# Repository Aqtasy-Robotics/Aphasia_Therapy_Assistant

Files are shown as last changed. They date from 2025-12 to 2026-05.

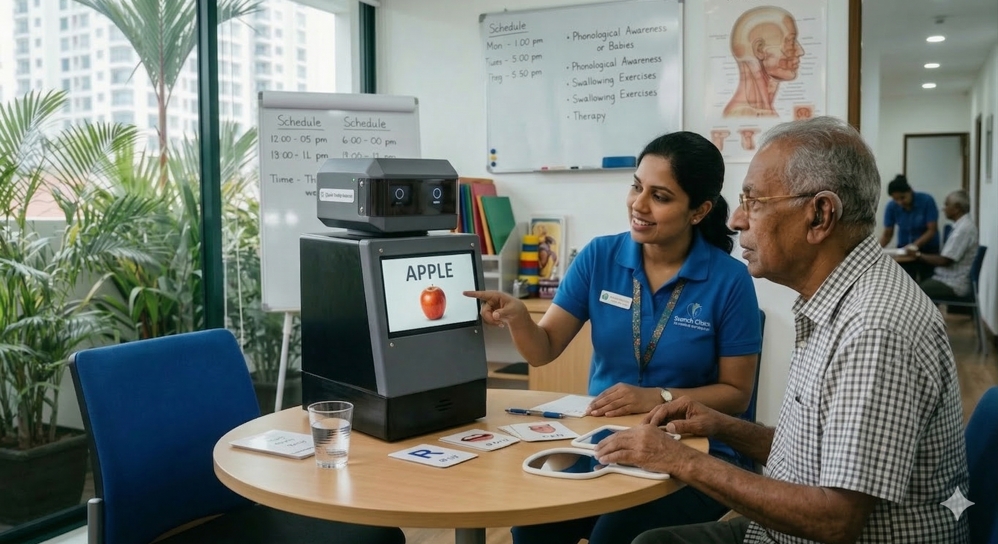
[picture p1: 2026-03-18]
frontend/src/assets/authentication_bgimage.png

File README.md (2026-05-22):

# Waabi — Aphasia Therapy Assistant

> **An AI-powered robotic companion that supports aphasia recovery through structured, conversational speech therapy sessions.**

---

## Table of Contents

- [Overview](#overview)
- [Features](#features)
- [Architecture](#architecture)
- [Repository Layout](#repository-layout)
- [Tech Stack](#tech-stack)
- [Getting Started](#getting-started)
  - [Prerequisites](#prerequisites)
  - [Quick Start: Kivy GUI (Robot)](#quick-start-kivy-gui-robot)
  - [Quick Start: FastAPI Bridge](#quick-start-fastapi-bridge)
  - [Quick Start: Frontend Web App](#quick-start-frontend-web-app)
- [Environment Variables](#environment-variables)
- [Data Flow](#data-flow)
- [Supabase Setup](#supabase-setup)

---

## Overview

Aphasia is a language disorder most commonly caused by stroke or brain injury, affecting a person's ability to speak, understand, read, and write. **Waabi** is a robotic therapy assistant designed to deliver consistent, engaging, and data-driven speech therapy exercises — bridging the gap between clinical appointments and at-home rehabilitation.

Waabi combines a LangGraph-based agentic therapy pipeline, a FastAPI communication bridge, a React web portal for therapists and patients, and a touchscreen-capable Kivy GUI that runs directly on the robot's hardware (e.g. a Raspberry Pi).

---

## Features

- **Agentic therapy sessions** — A LangGraph pipeline guides patients through structured speech exercises (perception → analysis → feedback → execution).
- **Real-time voice interaction** — Microphone capture, text-to-speech via Piper, and optional ElevenLabs Conversational AI integration.
- **Session reporting** — Completed sessions are automatically persisted to Supabase for therapist review.
- **Dual interfaces** — A Kivy touchscreen GUI for bedside/robot use and a React web app for therapist and patient portals.
- **Hardware–cloud bridge** — A FastAPI server mediates commands, status updates, UI events, and audio uploads between the robot and the cloud.
- **Progress tracking** — Recharts-powered dashboards in the web app let therapists monitor patient progress over time.
- **Role-based access** — Supabase Auth with protected routes for therapist and patient roles.

---

## Architecture

```
┌─────────────────────────────────────────────────────────┐
│                      Web App (React)                    │
│          Therapist Portal │ Patient Portal              │
└──────────────────┬──────────────────────────────────────┘
                   │ Supabase Auth (anon key)
                   ▼
┌─────────────────────────────────────────────────────────┐
│                   Supabase (PostgreSQL)                  │
│   profiles │ sessions │ session_reports │ robot-audio   │
└───────────────┬─────────────────────────────────────────┘
                │ service role key
                ▼
┌─────────────────────────────────────────────────────────┐
│             FastAPI Bridge  (backend/main.py)            │
│   GET /commands/{device_id}  │  POST /status            │
│   POST /audio/{device_id}    │  POST /ui-events         │
└──────────────────┬──────────────────────────────────────┘
                   │ HTTP polling
                   ▼
┌─────────────────────────────────────────────────────────┐
│         Hardware Execution Agent (Raspberry Pi)          │
│   hardware/execution_agent/main.py  │  run_gui.py       │
│   Kivy Touchscreen GUI + Drivers (speak, listen, UI)    │
└──────────────────┬──────────────────────────────────────┘
                   │
                   ▼
┌─────────────────────────────────────────────────────────┐
│          LangGraph Therapy Agent  (agentic/)             │
│   Perception → Analysis → Feedback → Execution          │
└─────────────────────────────────────────────────────────┘
```

---

## Repository Layout

```
Aphasia_Therapy_Assistant/
├── agentic/                    # LangGraph speech-therapy pipeline + Supabase helpers
│   └── graph.py                # Main session entrypoint (run_session_for_patient)
├── backend/
│   ├── main.py                 # FastAPI bridge: commands, status, audio, UI events
│   ├── requirements.txt
│   └── .env.example
├── frontend/                   # React + Vite web app (therapist / patient portals)
├── hardware/
│   └── execution_agent/        # Robot / Raspberry Pi software
│       ├── main.py             # Polling loop + hardware drivers
│       ├── run_gui.py          # Kivy launcher (therapy GUI + LangGraph)
│       ├── env_bootstrap.py    # .env merge order utility
│       ├── config.json
│       └── .env.example
├── ML/                         # Speech analysis experiments and research
├── integrations/
│   └── elevenlabs_convai/      # ElevenLabs Conversational AI integration
├── pipecat/                    # Optional real-time voice assistant stack
├── supabase/
│   └── migrations/             # SQL migrations (robot_ui_events, pipeline tables, etc.)
├── scripts/                    # Helper shell scripts
├── tests/                      # Test suite (pytest)
├── laptop_server.py            # Convenience server launcher
├── requirements.txt            # Root Python dependencies
├── requirements-dev.txt        # Dev/test dependencies
└── netlify.toml                # Frontend deployment config
```

---

## Tech Stack

| Layer | Technology |
|---|---|
| **Frontend** | React (Vite), TypeScript, Tailwind CSS, Recharts, React Router v6 |
| **Backend / Bridge** | Python, FastAPI, Uvicorn |
| **Therapy Agent** | LangGraph, Groq (LLM inference) |
| **Database & Auth** | Supabase (PostgreSQL), Supabase Storage |
| **Robot GUI** | Python, Kivy, kvlang |
| **TTS** | Piper (local), ElevenLabs (cloud) |
| **CI/CD** | GitHub Actions, Netlify |
| **Testing** | Pytest |

---

## Getting Started

### Prerequisites

- Python 3.10+
- Node.js 18+ (for the frontend)
- A [Supabase](https://supabase.com/) project with the required tables and storage bucket (see [Supabase Setup](#supabase-setup))
- A [Groq](https://console.groq.com/) API key
- PortAudio installed on the robot device (`sudo apt-get install portaudio19-dev`)

---

### Quick Start: Kivy GUI (Robot)

Run from **`hardware/execution_agent/`**:

```bash
python -m venv .venv
source .venv/bin/activate          # Windows: .venv\Scripts\activate
pip install -r requirements.txt

cp .env.example .env               # Fill in SERVER_URL, DEVICE_ID, Supabase & Groq keys
```

> **No microphone / headless testing?** Set `RUN_GUI_SKIP_PORTAUDIO_CHECK=1` in your `.env`.

```bash
python run_gui.py
```

The GUI will prompt for the patient's full name (must match a `profiles.full_name` row with `role = 'patient'` in Supabase). The LangGraph pipeline then runs the session and writes a report to `session_reports` on completion.

`.env` files are merged in this order (later files override earlier ones):

```
repo root .env → backend/.env → agentic/db/.env → execution_agent/.env → hardware/.env
```

---

### Quick Start: FastAPI Bridge

```bash
cd /path/to/Aphasia_Therapy_Assistant
python -m venv .venv
source .venv/bin/activate
pip install -r backend/requirements.txt

# Set SUPABASE_URL and SUPABASE_SERVICE_KEY in .env (repo root or backend/.env)
uvicorn backend.main:app --reload --app-dir .
```

The `--app-dir .` flag ensures `agentic` package imports resolve correctly from the repo root.

---

### Quick Start: Frontend Web App

```bash
cd frontend
npm install
cp .env.example .env.local         # Set VITE_SUPABASE_URL and VITE_SUPABASE_ANON_KEY
npm run dev
```

Open `http://localhost:5173` in your browser.

---

## Environment Variables

### Repo root `.env` *(recommended single source)*

| Variable | Description |
|---|---|
| `SUPABASE_URL` | Your Supabase project URL |
| `SUPABASE_SERVICE_KEY` | Supabase service role key (server-side only) |
| `GROQ_API_KEY` | Groq API key for LLM inference |

### `hardware/execution_agent/.env`

| Variable | Description |
|---|---|
| `SERVER_URL` | URL of the FastAPI bridge |
| `DEVICE_ID` | Stable identifier for the robot (e.g. `robot-pi-001` or a patient UUID) |
| Piper paths | Path to local TTS model files |

### `backend/.env`

| Variable | Description |
|---|---|
| `SUPABASE_URL` | Supabase project URL |
| `SUPABASE_SERVICE_KEY` | Service role key |
| `BRIDGE_PATIENT_PROFILE_ID` | *(Optional)* Patient `profiles.id` UUID. Use when `DEVICE_ID` is a label rather than a UUID; the bridge loads the patient's name for session greetings. |

> **Robot ID vs Patient ID:** `DEVICE_ID` identifies the robot in API paths. For the bridge greeting, either set `BRIDGE_PATIENT_PROFILE_ID` on the server, or set `DEVICE_ID` to the patient's `profiles.id` UUID directly (legacy behaviour).

---

## Data Flow

### A — Kivy GUI Therapy Session *(typical demo / standalone)*

1. Launch `run_gui.py` from `hardware/execution_agent/`.
2. Patient enters their name; the GUI looks up the matching `profiles` row in Supabase.
3. `agentic/graph.py` runs `run_session_for_patient` through the full LangGraph pipeline.
4. On completion, `persist_session_state` writes results to `session_reports`.
5. The FastAPI bridge is **not required** for session persistence in this path.

### B — Execution Agent + FastAPI Polling

1. Start the bridge: `uvicorn backend.main:app --reload --app-dir .`
2. Start the polling agent: `hardware/execution_agent/main.py` (with `polling` enabled in `config.json`).
3. The robot calls `GET /commands/{DEVICE_ID}`, executes actions, then posts to `POST /status`.
4. `POST /status` writes to `session_reports` only when `ack.result` includes `patient_id` and the full expected state fields. For complete session persistence, prefer the Kivy/LangGraph path.

### C — Web App

- `frontend/` authenticates via Supabase Auth using the **anon key** (set in Vite env).
- Therapists can view patient session reports, assign target words, and monitor progress.
- Patients can access their session history and exercises.

---

## Supabase Setup

1. **Apply migrations** from `supabase/migrations/` to your Supabase project (includes `robot_ui_events`, `agent_pipeline_steps`, and others).

2. **Ensure these tables exist:**
   - `profiles` — user accounts with a `role` column (`'therapist'` or `'patient'`) and `full_name`
   - `sessions` — therapy session definitions including `target_words`
   - `session_reports` — completed session results written by the agent

3. **Create a storage bucket** named `robot-audio` if you use robot audio upload functionality.

4. **Configure RLS (Row Level Security)** policies as appropriate for your deployment — therapists should read all patient records; patients should read only their own.

---

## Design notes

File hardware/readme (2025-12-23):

This is the folder for Hardware related work 
The Basic Hardware is to be used 
- Raspberry Pi 4 8GB
- Micro Phone 
- Speaker
- 7 Inch touch display(Body)
- 1.5 Inch OLED display (Face)
- Micro SD Card
- 3D Printed encoluser 
- Cabels,Screws and Nuts
- Power adapter

Raspberry Pi OS Installation Guide

This guide outlines the steps to install Raspberry Pi OS on a Raspberry Pi 4 for headless (remote) access via SSH.
Prerequisites

    Raspberry Pi 4

    MicroSD card (8GB minimum, 16GB+ recommended)

    Computer with SD card reader

    Network connection for initial setup

Installation Steps
1. Prepare Installation Medium

    Install Raspberry Pi Imager

        Download from raspberrypi.com/software

        Available for Windows, macOS, and Linux

    Insert SD Card

        Insert the microSD card into your computer's card reader

2. Configure and Write OS Image

    Launch Raspberry Pi Imager

    Select Device: Choose "Raspberry Pi 4"

    Choose OS: Select "Raspberry Pi OS (other)" → "Raspberry Pi OS Lite" (or your preferred variant)

    Select Storage: Choose your inserted SD card

    Configure Settings (Click gear icon or Ctrl+Shift+X):

        Enable SSH: Set password authentication

        Configure Wi-Fi (optional for wireless setup):

            Enter SSID and password

            Select your country

        Set username and password

        Configure locale settings if needed

    Write Image: Click "WRITE" and confirm to begin writing

3. Boot Raspberry Pi

    Eject SD card safely from your computer

    Insert SD card into Raspberry Pi 4

    Connect power to boot the Raspberry Pi

    Wait 1-2 minutes for initial boot process to complete

4. Remote Access

    SSH Access: Connect using your computer's terminal:
    bash

ssh username@raspberrypi.local

or use the IP address if known:
bash

ssh username@[IP_ADDRESS]

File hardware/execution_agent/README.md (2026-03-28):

# Aphasia Therapy Robot — Execution Agent v1

A Python-based execution agent that runs on a **Raspberry Pi 4**, communicates with a FastAPI backend over HTTP, and controls local hardware to deliver interactive aphasia therapy sessions.

> 📋 **For detailed implementation phases and development roadmap, see [`implementation_plan.md`](implementation_plan.md).**

| Component | Technology |
|---|---|
| TTS | Piper TTS (local ONNX) |
| Comms | HTTP REST polling (httpx → FastAPI) |
| Mic / Speaker | sounddevice + numpy |
| 7" Touch UI | Kivy (framebuffer / KMS) |
| 1.5" OLED Face | luma.oled (I2C or SPI) |
| Head Servos | gpiozero (GPIO 17 pan, GPIO 27 tilt) |

---

## Project Structure

```
execution_agent/
├── .env                       # Server URL, Device ID, model paths
├── config.json                # Polling rates, GPIO pins, volume, OLED addr
├── requirements.txt           # Python dependencies
├── main.py                    # Entry point & orchestrator
├── models/                    # Piper ONNX model files
│   └── en_US-lessac-medium.onnx
├── src/
│   ├── settings.py            # Pydantic settings loader
│   ├── dispatcher.py          # Command → driver router
│   ├── communication/
│   │   ├── api_client.py      # HTTP polling client
│   │   └── models.py          # ExecutionCommand / CommandAck schemas
│   ├── services/
│   │   ├── ear.py             # Microphone input (sounddevice)
│   │   ├── mouth.py           # Piper TTS + speaker output
│   │   ├── face.py            # OLED face expressions (luma.oled)
│   │   └── head.py            # Servo head movement (gpiozero)
│   └── ui/
│       ├── body_app.py        # Kivy 7" touch dashboard
│       └── body_app.kv        # Kivy layout file
├── assets/
│   ├── images/                # Face PNGs, therapy images
│   └── audio/                 # Sound effects
└── scripts/
    ├── install_dependencies.sh  # One-shot Pi setup (apt + venv)
    ├── install_portaudio_apt.sh # Debian/Ubuntu: PortAudio for mic (dev laptop)
    ├── setup.sh                 # Python virtualenv + pip requirements
    ├── run_agent_desktop.sh     # Pi Desktop: main.py + Kivy UI env vars
    ├── aphasia-robot-agent.desktop  # Template launcher (edit paths)
    └── robot.service            # systemd service unit
```

---

## Prerequisites

- **Raspberry Pi 4** (4 GB+ recommended) running **Raspberry Pi OS Lite** (Bookworm 64-bit)
- Python **3.10+** (ships with Bookworm)
- I2C enabled (`sudo raspi-config` → Interface Options → I2C → Enable) when using I2C OLED
- SPI enabled (`sudo raspi-config` → Interface Options → SPI → Enable) when using SPI OLED
- Official 7" touchscreen connected via DSI
- USB microphone + 3.5 mm / USB speaker

---

## Local MCP Server (STDIO)

You can expose local hardware controls as MCP tools for desktop agents.

### Install dependency

```bash
pip install -r requirements.txt
```

### Start MCP server

From `hardware/execution_agent`:

```bash
python -m mcp_server
```

### Tools exposed (v1)

- `health_check`
- `audio_list_devices`
- `audio_listen`
- `audio_speak`
- `ui_start`
- `ui_show`
- `ui_events_read`
- `ui_ready`

### Remote Raspberry Pi (via FastAPI bridge)

Use these from the **laptop** so commands run on the **Pi** (speaker, mic, Kivy). The bridge must be running (`uvicorn backend.main:app`) and the Pi must run `python main.py` with `SERVER_URL` pointing at that bridge.

- `bridge_health_remote`
- `bridge_enqueue_command`
- `bridge_speak_on_robot`
- `bridge_listen_on_robot`
- `bridge_show_ui_on_robot`

Full setup: **[`docs/BRIDGE_AND_MCP.md`](docs/BRIDGE_AND_MCP.md)**.

### Example MCP client command config

```json
{
  "mcpServers": {
    "waabi-hardware-local": {
      "command": "python",
      "args": ["-m", "mcp_server"],
      "cwd": "C:/Users/USER/Desktop/Aqtasy Robotics/Aphasia_Therapy_Assistant/hardware/execution_agent"
    }
  }
}
```

---

## Installation on Raspberry Pi

### 1. Clone the Repository

```bash
cd ~
git clone <your-repo-url> execution_agent
cd execution_agent
```

### 2. Run the System Dependencies Script

```bash
chmod +x scripts/install_dependencies.sh
sudo scripts/install_dependencies.sh
```

This installs the following apt packages (among others):

| Package | Purpose |
|---|---|
| `python3-venv` | Virtual environment support |
| `libportaudio2`, `portaudio19-dev` | PortAudio for sounddevice |
| `libatlas-base-dev` | Optimised BLAS for numpy on ARM |
| `libjpeg-dev`, `libpng-dev` | Image libraries for Pillow |
| `libsdl2-dev`, `libsdl2-image-dev`, `libsdl2-mixer-dev`, `libsdl2-ttf-dev` | SDL2 for Kivy |
| `i2c-tools`, `python3-smbus` | I2C for OLED |
| `libgpiod2` | GPIO for gpiozero |
| `espeak-ng` | Fallback TTS phonemiser (used by Piper) |

### 3. Create a Virtual Environment

```bash
bash scripts/setup.sh
source .venv/bin/activate
```

> **Note:** On the Pi, `numpy` and `scipy` will build from wheels — this can take a few minutes on first install.

### 4. Download the Piper TTS Model

```bash
mkdir -p models
# English (US) — lessac medium quality (recommended for Pi 4)
wget -O models/en_US-lessac-medium.onnx \
  https://huggingface.co/rhasspy/piper-voices/resolve/main/en/en_US/lessac/medium/en_US-lessac-medium.onnx

wget -O models/en_US-lessac-medium.onnx.json \
  https://huggingface.co/rhasspy/piper-voices/resolve/main/en/en_US/lessac/medium/en_US-lessac-medium.onnx.json
```

### 5. Configure Environment Variables

Create a `.env` file at the project root:

```bash
nano .env
```

Minimum variables:

```dotenv
SERVER_URL=http://<your-server-ip>:8000
DEVICE_ID=robot-pi-001
PIPER_MODEL_PATH=/home/pi/execution_agent/models/en_US-lessac-medium.onnx
LOG_LEVEL=INFO
```

### 6. Test the Agent (Phase-by-Phase)

The project is designed to be tested incrementally on the Pi, following the phases outlined in `implementation_plan.md`. This allows you to verify each component before moving to the next.

#### Phase 1: Mock Drivers (No Hardware Required)

Test that the agent boots and all drivers initialize in mock mode:

```bash
python main.py
```

**Expected output:**
```
INFO  | Execution Agent starting…
INFO  | Device: robot-pi-001
INFO  | Server: http://192.168.1.100:8000
INFO  | Drivers loaded (mock mode): ear, mouth, face, head, body
INFO  | Entering idle loop with interval=2.0 s…
```

**Verification checklist:**
- [ ] Agent starts without errors
- [ ] All drivers report "mock mode" in logs
- [ ] Settings load correctly from `.env` and `config.json`
- [ ] Graceful shutdown works (Ctrl+C)

#### Phase 2: API Client & Polling (Requires FastAPI Backend)

**Prerequisites:** A FastAPI backend server running and accessible at `SERVER_URL`.

Test that the agent can poll for commands and send acknowledgements:

```bash
python main.py
```

**Expected behavior:**
- Agent polls `GET /commands/{device_id}` every 2 seconds
- Logs show connection status to the backend
- Commands are received and dispatched (still using mock drivers)
- Acknowledgements are sent back to the server

**Verification checklist:**
- [ ] Agent successfully connects to backend (check `/health` endpoint)
- [ ] Polling loop runs without errors
- [ ] Commands are received and logged
- [ ] Mock drivers execute commands (logged, not hardware)
- [ ] Acknowledgements are sent to `/status` endpoint

**Test with a simple backend:**
```python
# On your laptop/server, run a test FastAPI server
from fastapi import FastAPI
app = FastAPI()

@app.get("/commands/robot-pi-001")
def get_command():
    return {"command_id": "test-1", "action": "speak", "payload": {"text": "Hello"}}

@app.post("/status")
def post_status(ack: dict):
    print(f"Received: {ack}")
    return {"ok": True}
```

#### Phase 3: Audio Hardware (Requires USB Mic + Speaker)

**Prerequisites:** USB microphone and speaker connected to the Pi.

Test real audio input/output:

```bash
python main.py
```

**Verification checklist:**
- [ ] `mouth.speak("Hello")` plays audio through speaker
- [ ] `ear.listen(5)` records 5 seconds from microphone
- [ ] Audio sample rate matches `config.json` (22050 Hz)
- [ ] Piper TTS model loads successfully (< 5 seconds)
- [ ] Recorded audio can be uploaded to backend

**Test commands:**
- Send a `speak` command from backend → verify audio plays
- Send a `listen` command → verify recording works and uploads

#### Phase 4: Kivy UI (Requires 7" Touchscreen)

**Prerequisites:** Official 7" Raspberry Pi touchscreen connected via DSI.

Test the touchscreen dashboard:

```bash
# Ensure display is configured for KMS/DRM
export KIVY_WINDOW=sdl2
export KIVY_GL_BACKEND=sdl2
python main.py
```

**Verification checklist:**
- [ ] Kivy app launches fullscreen on 7" display
- [ ] `show_ui` command updates screen content
- [ ] Touch input is responsive
- [ ] App runs alongside polling loop without blocking

#### Phase 5: GPIO & OLED (Requires Servos + OLED Display)

**Prerequisites:**
- Pan/tilt servos connected to GPIO 17 and 27
- OLED display connected via I2C (address 0x3C)
- I2C enabled: `sudo raspi-config` → Interface Options → I2C → Enable

Test physical hardware:

```bash
# Verify I2C connection first
sudo i2cdetect -y 1  # Should show OLED at 0x3C

python main.py
```

**Verification checklist:**
- [ ] `head.move(pan=45, tilt=0)` physically rotates pan servo
- [ ] `face.show("happy")` displays expression on OLED
- [ ] GPIO pins match `config.json` values
- [ ] Servos respect safety limits (no jitter at rest)
- [ ] OLED initializes cleanly and recovers from bus errors

**Test commands:**
- `move_head` with various pan/tilt values
- `show_face` with different expressions (happy, sad, neutral, etc.)

---

## Testing on Laptop (Development Mode)

You can develop and test on any Linux/macOS/Windows machine. Hardware-dependent libraries (`gpiozero`, `luma.oled`) are automatically mocked when imports fail.

```bash
# Clone & set up
git clone <your-repo-url> execution_agent
cd execution_agent
python3 -m venv .venv && source .venv/bin/activate
pip install -r requirements.txt

# Run with mock drivers (Phase 1 equivalent)
python main.py
```

All drivers will automatically fall back to mock mode, allowing you to test the full command flow without hardware.

### Microphone / `run_gui.py` — PortAudio required

The LangGraph session records audio with **`sounddevice`**, which needs the **PortAudio** system library. `run_gui.py` checks for PortAudio on startup and exits with instructions if it is missing.

**Debian / Ubuntu (one command):**

```bash
cd execution_agent   # folder containing main.py
sudo bash scripts/install_portaudio_apt.sh
```

Or manually: `sudo apt install -y libportaudio2 portaudio19-dev`

Then restart `run_gui.py`. The Pi image script [`scripts/install_dependencies.sh`](scripts/install_dependencies.sh) already includes these packages.

### LangGraph therapy session (`run_gui.py`)

[`run_gui.py`](run_gui.py) loads **repo-root** `../.env` before Kivy starts so **`GROQ_API`**, **`SUPABASE_URL`**, **`SUPABASE_SERVICE_KEY`**, etc. are available when you tap the mic and [`agentic/graph.py`](../agentic/graph.py) runs. Without a valid `.env`, perception (Groq) or Supabase lookups will fail.

From the **repository root** (parent of this folder), you can also use [`../scripts/run_gui_langgraph.sh`](../scripts/run_gui_langgraph.sh) to set `PYTHONPATH` and run the GUI.

### Desktop launcher (full agent + UI + backend)

1. Edit paths in [`scripts/aphasia-robot-agent.desktop`](scripts/aphasia-robot-agent.desktop) (`Exec` and `Path`) to match your install.
2. `chmod +x scripts/run_agent_desktop.sh scripts/aphasia-robot-agent.desktop`
3. Copy the `.desktop` file to `~/Desktop` or `~/.local/share/applications/`, then mark it trusted / allow executing.

[`run_agent_desktop.sh`](scripts/run_agent_desktop.sh) sets `EXECUTION_AGENT_START_UI=1`, Kivy SDL2 env vars, and runs `main.py` (requires `polling.enabled` and `.env` for FastAPI).

### UI events → FastAPI

When polling is enabled, touch events from Kivy are **POST**ed to **`POST /ui-events/{device_id}`** on the backend. The FastAPI app in [`backend/main.py`](../backend/main.py) logs them. Set **`BRIDGE_TEST_SHOW_UI=1`** on the server to return a test `show_ui` command from **`GET /commands/{device_id}`**.

---

## Running as a System Service

### Install the systemd Unit

Edit `scripts/robot.service` if needed so `WorkingDirectory`, `ExecStart`, and `User` match where you cloned the repo (paths must point at the folder that contains `main.py`, `config.json`, and `.venv`).

```bash
cd /home/pi/execution_agent   # your install path
sudo cp scripts/robot.service /etc/systemd/system/
sudo systemctl daemon-reload
sudo systemctl enable robot.service
sudo systemctl start robot.service
```

**OLED face on boot (no backend):** In `config.json` set `"polling": { "enabled": false, ... }` and `"oled": { "standalone_math_eyes": true, ... }` with the same SPI/SH1107 options as `hardware_tests/pan_oled_phase5/test_config.json` (`interface`, `oled_driver`, `rotate`, `eye_layout`, `eyes_bias_x`, GPIO pins). The agent’s main loop stays alive while the OLED task animates; `Restart=always` restarts the process if it ever crashes.

### Check Logs

```bash
sudo journalctl -u robot.service -f
```

---

## Configuration Reference

### `.env`

| Variable | Description | Example |
|---|---|---|
| `SERVER_URL` | FastAPI backend base URL | `http://192.168.1.100:8000` |
| `DEVICE_ID` | Unique robot identifier | `robot-pi-001` |
| `PIPER_MODEL_PATH` | Path to Piper ONNX model | `models/en_US-lessac-medium.onnx` |
| `PIPER_MODEL_CONFIG` | Path to Piper model config JSON | `models/en_US-lessac-medium.onnx.json` |
| `LOG_LEVEL` | Logging verbosity | `DEBUG` / `INFO` / `WARNING` |

### `config.json`

| Section | Key | Default | Description |
|---|-----|---|---|
| `polling` | `interval_seconds` | `2.0` | How often to poll the server |
| `polling` | `enabled` | `true` | Enable/disable backend polling loop |
| `polling` | `timeout_seconds` | `5.0` | HTTP request timeout |
| `polling` | `max_retries` | `3` | Retries before back-off |
| `audio` | `sample_rate` | `22050` | Recording/playback sample rate |
| `audio` | `channels` | `1` | Mono |
| `audio` | `volume` | `0.8` | Playback gain (0.0–1.0) |
| `gpio` | `servo_pan_pin` | `17` | BCM pin for pan servo |
| `gpio` | `servo_min_pulse_width` | `0.0005` | Pan servo minimum pulse width |
| `gpio` | `servo_max_pulse_width` | `0.0025` | Pan servo maximum pulse width |
| `oled` | `i2c_address` | `0x3C` | OLED I2C address |
| `oled` | `interface` | `i2c` | OLED bus interface (`i2c` or `spi`) |
| `oled` | `oled_driver` | `ssd1351` | Display controller driver |
| `oled` | `spi_port` / `spi_device` | `0` / `0` | Linux SPI bus and CS |
| `oled` | `spi_gpio_dc` / `spi_gpio_rst` | `24` / `25` | GPIO pins for D/C and RESET |
| `oled` | `standalone_math_eyes` | `false` | Run local eye animation without backend commands |
| `oled` | `width` / `height` | `128` / `128` | OLED resolution |
| `display` | `width` / `height` | `800` / `480` | Kivy display resolution |

---

## Wiring Diagram (Quick Reference)

```
Raspberry Pi 4 GPIO Header
──────────────────────────
Pin 1  (3.3V)     → OLED VCC
Pin 3  (GPIO 2)   → OLED SDA  (I2C Data)
Pin 5  (GPIO 3)   → OLED SCL  (I2C Clock)
Pin 6  (GND)      → OLED GND
Pin 11 (GPIO 17)  → Pan Servo Signal   (Orange wire)
Pin 13 (GPIO 27)  → Tilt Servo Signal  (Orange wire)
Pin 2  (5V)       → Servo VCC          (Red wire, via external 5V supply recommended)
Pin 14 (GND)      → Servo GND          (Brown wire)
USB Port          → USB Microphone
3.5mm Jack / USB  → Speaker
DSI Port          → 7" Official Touchscreen
```

> ⚠️ **Important:** Power servos from an external 5V supply to avoid brownouts on the Pi. Share a common ground with the Pi.

### SPI OLED Quick Wiring (7-pin module)

For a 7-pin SPI OLED (`GND, VCC, D0, D1, RST, DC, CS`) on Raspberry Pi:

- `GND` -> Pi GND
- `VCC` -> Pi 3.3V (or module-safe 5V if your board supports it)
- `D0 (CLK)` -> GPIO11 / SPI0 SCLK (physical pin 23)
- `D1 (MOSI)` -> GPIO10 / SPI0 MOSI (physical pin 19)
- `RST` -> configurable GPIO (default in config: BCM 25 / physical pin 22)
- `DC` -> configurable GPIO (default in config: BCM 24 / physical pin 18)
- `CS` -> GPIO8 / SPI0 CE0 (physical pin 24, `spi_device=0`) or GPIO7 / CE1 (`spi_device=1`)

---

## License

This project is for academic / research use as part of the Aphasia Therapy Robot system.

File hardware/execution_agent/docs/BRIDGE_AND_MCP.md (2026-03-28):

# Laptop agents (MCP) + Raspberry Pi UI / mic / speaker

This flow uses the **FastAPI bridge** (`backend/main.py`) as a command queue:

1. **Laptop:** Claude / MCP calls `bridge_*_on_robot` tools → HTTP `POST /commands/{device_id}/enqueue`
2. **Bridge:** Stores commands in memory (FIFO per `device_id`)
3. **Pi:** `execution_agent/main.py` polls `GET /commands/{device_id}` → `Dispatcher` runs `speak` / `listen` / `show_ui` **on the Pi** (speaker, mic, Kivy)

## Prerequisites

- Same repo on laptop and Pi (or copy `hardware/execution_agent` + `backend` as needed)
- Pi and laptop on the same LAN (or VPN)
- Root `.env` with `SUPABASE_URL` and `SUPABASE_SERVICE_KEY` (for the bridge server)
- Optional: `BRIDGE_COMMAND_API_KEY` (same value in bridge env and laptop `execution_agent/.env` for MCP)

## 1) Run the bridge on the **laptop** (or any server the Pi can reach)

From repo root:

```powershell
cd "C:\Users\USER\Desktop\Aqtasy Robotics\Aphasia_Therapy_Assistant"
python -m venv .venv
.\.venv\Scripts\Activate.ps1
pip install -r backend/requirements.txt
pip install -r requirements.txt
```

If `backend/requirements.txt` is minimal, ensure you have: `fastapi`, `uvicorn`, `supabase`, `python-dotenv`, `pydantic` (install errors will tell you).

Start API (replace `0.0.0.0` so the Pi can connect; use your laptop LAN IP in Pi `.env`):

```powershell
uvicorn backend.main:app --host 0.0.0.0 --port 8000
```

Optional security (recommended):

```dotenv
# repo root .env or backend/.env
BRIDGE_COMMAND_API_KEY=your-long-random-secret
```

## 2) Configure the **Raspberry Pi** `execution_agent`

Edit `hardware/execution_agent/.env`:

- `SERVER_URL=http://<LAPTOP_LAN_IP>:8000` (must match where uvicorn runs)
- `DEVICE_ID=robot-pi-001` (or any stable label; must match what you pass from MCP)
- `PIPER_MODEL_PATH=...` (path to Piper ONNX on the Pi)
- Start Kivy with the agent:

```dotenv
EXECUTION_AGENT_START_UI=1
```

Edit `hardware/execution_agent/config.json` → ensure `polling.enabled` is `true` (default in your template).

### Run on the Pi (must run **on the Raspberry Pi**)

```bash
cd ~/Aphasia_Therapy_Assistant/hardware/execution_agent
source .venv/bin/activate   # or your venv
export EXECUTION_AGENT_START_UI=1
python main.py
```

The Pi will poll the bridge and execute commands on **local** speaker, mic, and Kivy.

## 3) Configure **MCP on the laptop** (Claude Desktop / Cursor)

Same machine that runs MCP needs `hardware/execution_agent/.env`:

- `SERVER_URL=http://<LAPTOP_LAN_IP>:8000` (same bridge URL; can be `http://127.0.0.1:8000` if MCP and uvicorn are on the same PC)
- `DEVICE_ID=robot-pi-001` (same as Pi)
- If you set `BRIDGE_COMMAND_API_KEY` on the server, add the same to this `.env`:

```dotenv
BRIDGE_COMMAND_API_KEY=your-long-random-secret
```

Run MCP:

```powershell
cd "C:\Users\USER\Desktop\Aqtasy Robotics\Aphasia_Therapy_Assistant\hardware\execution_agent"
python -m mcp_server
```

Or register `python -m mcp_server` in Claude Desktop with `cwd` set to this folder.

## 4) MCP tools to use (remote Pi)

| Tool | Purpose |
|---|---|
| `bridge_health_remote` | Check bridge `GET /health` |
| `bridge_speak_on_robot` | TTS on Pi speaker |
| `bridge_listen_on_robot` | Record on Pi mic (upload depends on `ear` + backend) |
| `bridge_show_ui_on_robot` | Kivy screen on Pi |
| `bridge_enqueue_command` | Generic `speak` / `listen` / `show_ui` / … |

Local-only tools (`ui_show`, `audio_speak`, …) still affect **only the machine running MCP**, not the Pi.

## 5) LangGraph / “agent on laptop”

This bridge queue drives **hardware** on the Pi. **LangGraph** (`agentic/graph.py`) is not automatically started by MCP. To run therapy logic on the laptop, call your Python entrypoint separately (e.g. `run_session_for_patient`) or add a future MCP tool that wraps it; use `bridge_speak_on_robot` / `bridge_listen_on_robot` from your agent code when you want Pi I/O.

## Troubleshooting

- **Pi never gets commands:** `SERVER_URL` on Pi must reach the laptop; firewall must allow port 8000; `DEVICE_ID` must match enqueue path.
- **401 on enqueue:** Set `BRIDGE_COMMAND_API_KEY` on server and same key in laptop `.env` for MCP.
- **No UI on Pi:** Set `EXECUTION_AGENT_START_UI=1` and ensure Kivy/display works on the Pi.

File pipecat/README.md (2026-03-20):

# Pipecat Aphasia Voice Assistant

This module provides a Pipecat-based, real-time voice assistant designed for **post-therapy support** for aphasia and related speech disorders.

It is intentionally tuned for:

- short, clear responses
- one-question-at-a-time pacing
- confirmation loops when speech is unclear
- supportive coaching (not diagnosis)

## What this bot does

- Listens to patient speech (Deepgram STT)
- Generates supportive responses (Groq LLM)
- Speaks back naturally (Cartesia TTS)
- Runs over Pipecat WebRTC transport for low-latency voice interaction

## Safety boundaries

The agent is configured to:

- avoid medical diagnosis or medication advice
- escalate to emergency services/caregiver language for urgent warning signs
- maintain a therapist-aligned coaching tone

This is **not** a replacement for clinician care.

## Project files

- `bot.py` - main Pipecat voice agent
- `.env.example` - required API variables
- `requirements.txt` - Python dependencies

## Quick start (Windows PowerShell)

From this folder:

```powershell
python -m venv .venv
.\.venv\Scripts\Activate.ps1
pip install -r requirements.txt
Copy-Item .env.example .env
```

Open `.env` and set:

- `DEEPGRAM_API_KEY`
- `GROQ_API_KEY`
- `CARTESIA_API_KEY`

Then run:

```powershell
python bot.py
```

You should see a local WebRTC URL in logs (typically `http://localhost:7860/client`) to connect from browser.

## Configuration for therapists

Use environment variables to tailor behavior:

- `GROQ_MODEL` - e.g. "llama-3.3-70b-versatile"
- `THERAPY_FOCUS` - e.g. "word retrieval and sentence initiation"
- `ASSISTANT_LANGUAGE_HINT` - e.g. "Use simple Spanish and short phrases"
- `ASSISTANT_NAME` - custom assistant name for familiarity

## Next improvements you can add

- Persist session summaries to your backend for therapist review
- Add personalized phrase banks from each patient's home program
- Add visual fallback prompts when voice confidence is low
- Add caregiver mode for guided home practice

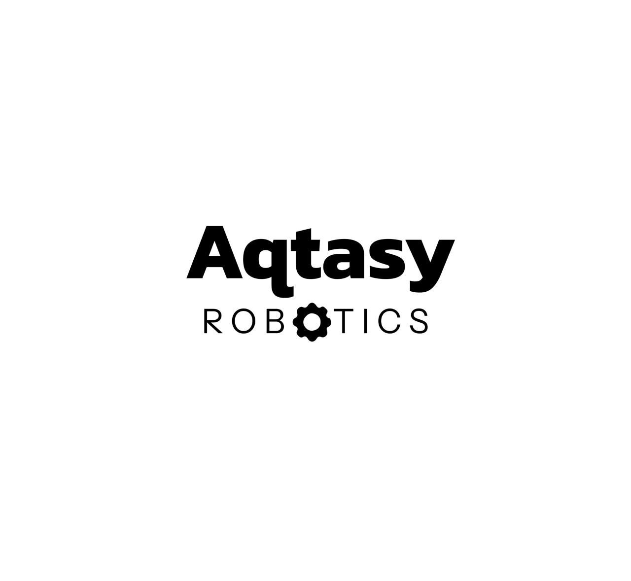
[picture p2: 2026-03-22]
hardware/execution_agent/WhatsApp Image 2026-03-22 at 8.28.11 PM.jpeg

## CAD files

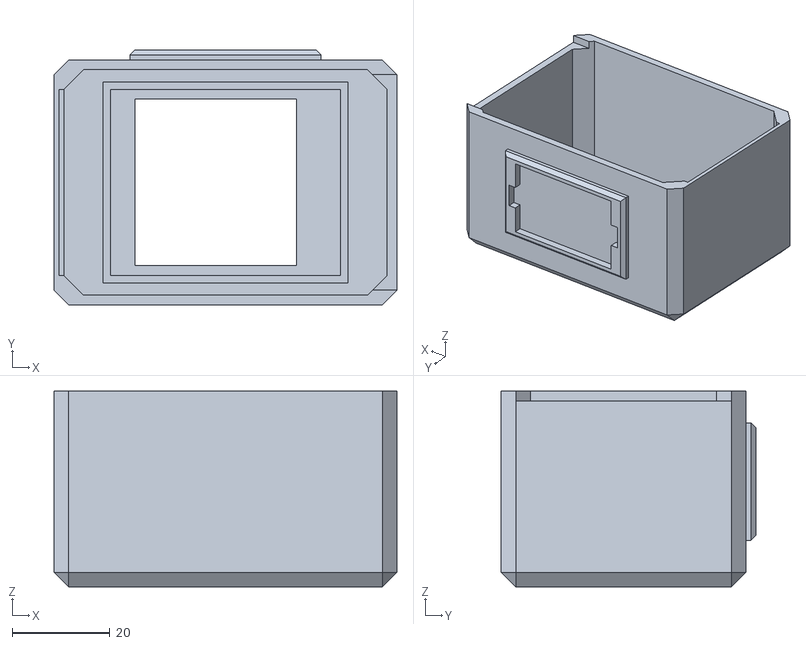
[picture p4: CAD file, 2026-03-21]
hardware/Waabi_design/Skeleton_frameV1/waabi_frame-Body011.stl
70.0 x 52.0 x 40.0

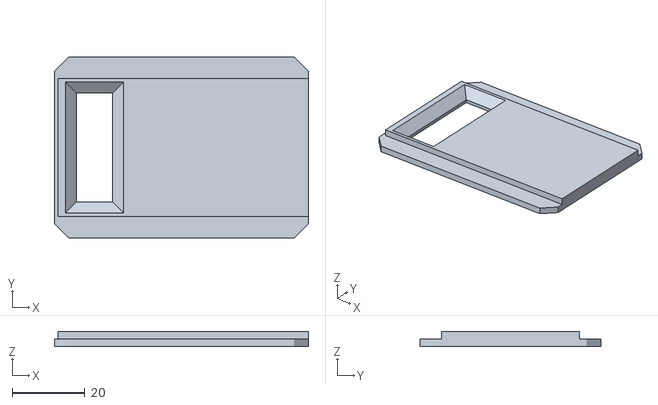
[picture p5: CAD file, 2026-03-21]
hardware/Waabi_design/Skeleton_frameV1/waabi_frame-Body012.stl
70.0 x 50.0 x 4.00

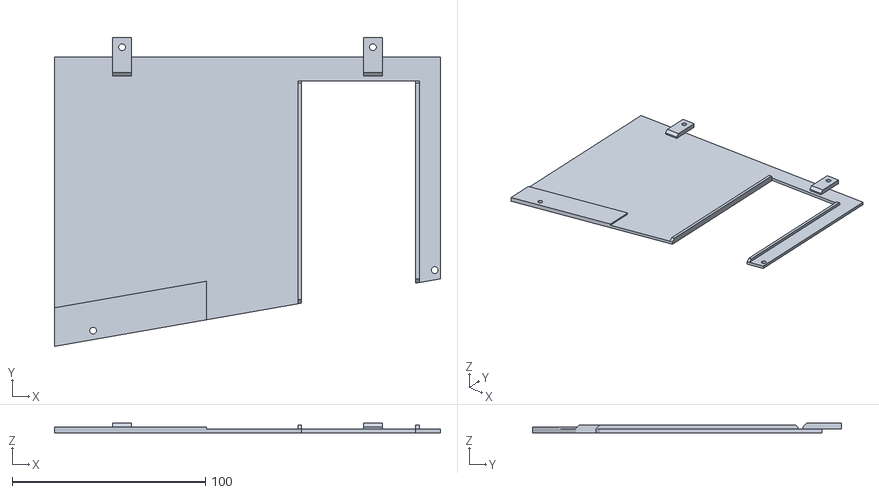
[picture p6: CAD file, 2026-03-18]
hardware/Waabi_design/Skeleton_frameV1/waabi_frame-leftside_plate.stl
200.0 x 160.0 x 5.00

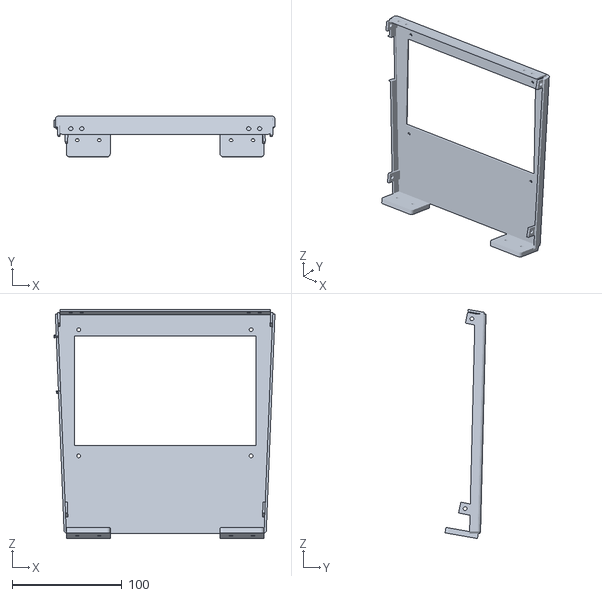
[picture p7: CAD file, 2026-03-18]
hardware/Waabi_design/Skeleton_frameV1/waabi_frame-Front_plate.stl
201.2 x 37.4 x 208.6

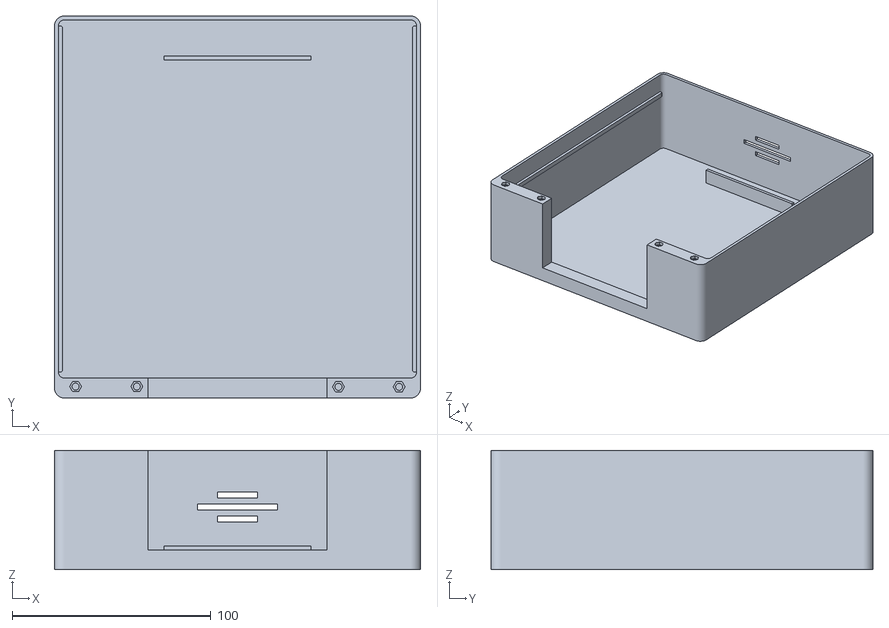
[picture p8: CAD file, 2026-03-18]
hardware/Waabi_design/Skeleton_frameV1/waabi_frame-BaseV2.stl
184.0 x 192.0 x 60.0

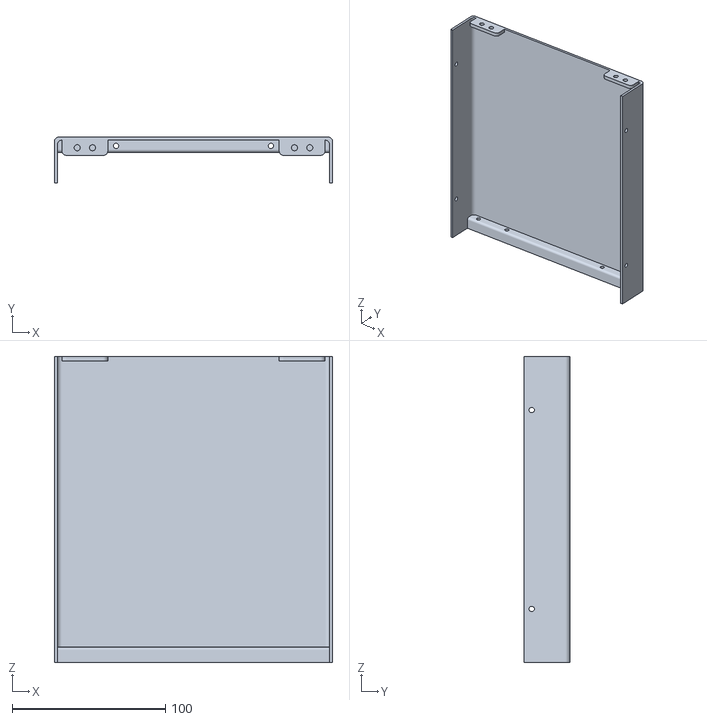
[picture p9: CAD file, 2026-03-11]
hardware/Waabi_design/Skeleton_frameV1/waabi_frame-Back_plate.stl
182.0 x 30.0 x 200.0

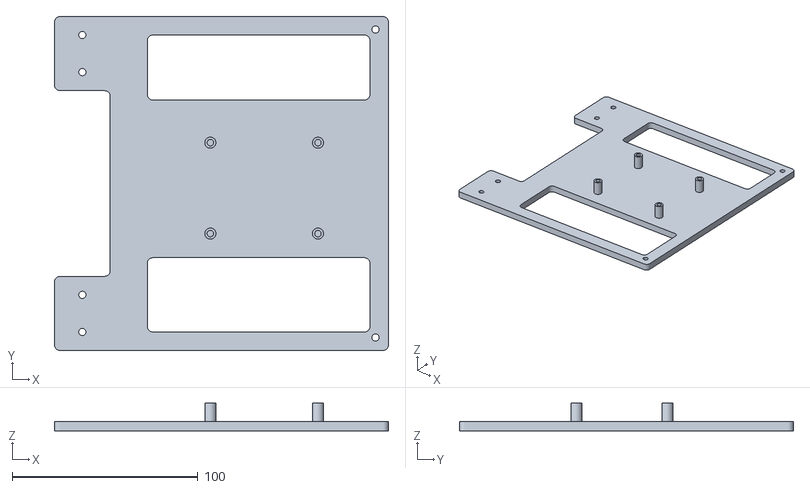
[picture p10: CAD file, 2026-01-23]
hardware/Waabi_design/Skeleton_frameV1/waabi_base_skeleton.stl
180.0 x 180.0 x 15.0

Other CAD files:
hardware/Waabi_design/Skeleton_frameV1/waabi_frame-Body.stl

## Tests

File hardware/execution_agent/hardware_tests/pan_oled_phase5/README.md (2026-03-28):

Pan+Eyes Physical Test (Phase 5)
================================

This folder is meant to be copied to your Raspberry Pi *as-is*.
It provides two small scripts:
- `test_pan_servo.py`: sweep the pan servo and verify clamping + movement
- `test_oled_eyes.py`: render procedural (code-generated) eyes to the OLED

Files you should upload/copy:
- `test_pan_servo.py`
- `test_oled_eyes.py`
- `test_config.json`
- `requirements.txt`
- this `README.md`

1) Copy to the Pi
-------------------
From your dev machine, run something like:

```bash
scp -r "execution_agent/hardware_tests/pan_oled_phase5" pi@<PI_IP>:~/
```

Then `cd` into the folder on the Pi:

```bash
cd ~/pan_oled_phase5
```

2) Install dependencies
------------------------
```bash
python3 -m pip install --upgrade pip
pip install -r requirements.txt
```

If you already have them installed system-wide, this can be skipped.

3) Edit `test_config.json` (if needed)
---------------------------------------
Defaults match the repo `execution_agent/config.json`.
If your wiring differs, update:
- `gpio.servo_pan_pin`
- `gpio.servo_min_pulse_width` / `gpio.servo_max_pulse_width`
- `oled.interface` (`i2c` or `spi`)
- `oled.i2c_address` / `oled.rotate` / `oled_driver` (if needed)
- SPI modules: `oled.spi_port`, `oled.spi_device`, `oled.spi_gpio_dc`, `oled.spi_gpio_rst`
- **Dual OLED mode:** if `oled_left` + `oled_right` exist in config, the script drives
  two displays and renders **one eye per display**.
  - Left eye display: `oled_left` (recommended CE0 / `spi_device: 0`)
  - Right eye display: `oled_right` (recommended CE1 / `spi_device: 1`)
  - Recommended dual pin map:
    - shared: `SCL->GPIO11`, `SDA->GPIO10`, `VCC->3V3`, `GND->GND`
    - left: `CS->GPIO8(CE0)`, `DC->GPIO24`, `RST->GPIO25`
    - right: `CS->GPIO7(CE1)`, `DC->GPIO23`, `RST->GPIO22`
- **Orientation:** `oled.rotate` — luma uses `0..3` (steps of 90° clockwise). Try `1`, `2`, or `3` if the face is sideways in your enclosure.
- **Eye position:** `oled.eye_layout` — `horizontal` (default) or `vertical` (stacked, good for portrait mounts). `oled.eyes_bias_x` — `-1.0`..`1.0`; **negative shifts both eyes left**, positive shifts right.

4) Test the pan servo
----------------------
```bash
python3 test_pan_servo.py
```

Optional flags:
- `--duration_s` (default: sweep once)
- `--pan_min`, `--pan_max`, `--step_deg`
- `--speed` (`slow|normal|fast`)

5) Test the OLED (eyes)
------------------------
```bash
python3 test_oled_eyes.py --duration 5.0 --expression neutral
```

For dual OLED (`oled_left` + `oled_right` in config), same command works and renders
one eye on each display:

```bash
python3 test_oled_eyes.py --config test_config.json --duration 15 --expression auto
```

Optional flags:
- `--duration` seconds (default: 3.0)
- `--expression` one of `neutral|happy|sad|thinking|surprised|listening` (default: auto cycle)
- `--gaze_x`, `--gaze_y` in range `[-1.0, 1.0]`

6) Troubleshooting quick checks
--------------------------------
Servo issues:
- Double-check the servo signal wire is on the BCM pin you set in `gpio.servo_pan_pin`.
- Ensure the servo has a suitable 5V supply (do not power servos from the Pi directly if unstable).

OLED issues:

- **`ModuleNotFoundError: No module named 'RPi'`** (SPI path): install GPIO support in the same venv — `pip install RPi.GPIO` (also listed in `requirements.txt`). Luma uses **RPi.GPIO** for SPI **DC** and **RST** lines.

- **Static / snow on a 128x128 blue 7-pin SPI board:** that panel is almost always **SH1107** (monochrome), not **SSD1351** (color). Use `"oled_driver": "sh1107"` with `"interface": "spi"`. Using `ssd1351` on SH1107 hardware produces garbage pixels.
- Confirm I2C is enabled: `sudo raspi-config` -> Interface Options -> I2C -> Enable.
- Confirm the OLED address (common is `0x3C` or `0x3D`).
- **`GME128128-01` / 1.5\" SH1107 IIC:** use `"oled_driver": "sh1107"`. The script uses
  the **u8g2** `SH1107 128x128` init (not luma/Adafruit). Set `"column_x_offset": 96`
  (default); if the image is horizontally wrong, try **`0`** (see u8g2 issue \#2581).
- Permissions: user must access `/dev/i2c-*` — `sudo usermod -aG i2c $USER` then re-login,
  or run once with `sudo` to verify.
- Slow bus: in `/boot/firmware/config.txt` add `dtparam=i2c_arm_baudrate=50000` and reboot.
- If your display controller is not SSD1351, set `oled_driver` in `test_config.json`:
  - `ssd1351` (default)
  - `sh1106`

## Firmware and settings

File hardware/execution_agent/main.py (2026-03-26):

"""Main entry point for the Aphasia Therapy Robot Execution Agent."""

import asyncio
import os
import signal
import sys
from pathlib import Path

# Enable Kivy virtual keyboard for touchscreen text input (dock = keyboard at bottom).
os.environ.setdefault("KCFG_KIVY_KEYBOARD_MODE", "dock")
os.environ.setdefault("KCFG_KIVY_KEYBOARD_LAYOUT", "qwerty")

from loguru import logger

from src.communication.api_client import ApiClient
from src.communication.models import ActionEnum
from src.dispatcher import Dispatcher
from src.services.audio_utils import list_audio_devices
from src.services.ear import listen
from src.services.face import (
    maybe_start_standalone_face,
    show_face,
    shutdown_face,
    stop_standalone_face,
)
from src.services.head import move_head, shutdown_head
from src.services.mouth import speak
from src.ui.body_app import (
    dequeue_ui_events,
    has_pending_ui_events,
    maybe_start_ui_from_env,
    show_ui,
)
from src.settings import load_settings_or_exit

# Global state
running = True


def handle_shutdown(signum, frame):
    """Handle shutdown signals gracefully."""
    global running
    logger.info(f"Received signal {signum}, initiating graceful shutdown...")
    running = False


def setup_logging(log_level: str, project_root: Path):
    """
    Configure loguru logger with console and file sinks.

    Args:
        log_level: Logging level (DEBUG, INFO, WARNING, ERROR)
        project_root: Root directory of the project
    """
    # Remove default logger
    logger.remove()

    # Console sink with color and formatting
    logger.add(
        sys.stderr,
        format="<green>{time:YYYY-MM-DD HH:mm:ss}</green> | <level>{level: <8}</level> | <level>{message}</level>",
        level=log_level,
        colorize=True,
    )

    # File sink - try /var/log first, fallback to logs/ directory
    log_file = Path("/var/log/execution_agent.log")
    if not log_file.parent.exists() or not os.access(log_file.parent, os.W_OK):
        # Fallback to project logs directory
        logs_dir = project_root / "logs"
        logs_dir.mkdir(exist_ok=True)
        log_file = logs_dir / "execution_agent.log"

    logger.add(
        log_file,
        format="{time:YYYY-MM-DD HH:mm:ss} | {level: <8} | {message}",
        level=log_level,
        rotation="10 MB",
        retention="5",
        compression="zip",
    )


async def main():
    """Main async entry point."""
    global running

    # Get project root (directory containing main.py)
    project_root = Path(__file__).parent

    # Load settings (exits on error)
    logger.info("Loading configuration...")
    settings = load_settings_or_exit()

    # Setup logging with loaded log level
    setup_logging(settings.log_level, project_root)
    maybe_start_ui_from_env(project_root)

    # Print startup banner
    banner = f"""
╔════════════════════════════════════════╗
║   Aphasia Therapy Robot - Agent v1    ║
╚════════════════════════════════════════╝
Device ID: {settings.device_id}
Server URL: {settings.server_url}
Polling Interval: {settings.polling.interval_seconds}s
Log Level: {settings.log_level}
"""
    logger.info(banner)

    # Log configuration summary
    logger.info("Configuration loaded successfully")
    logger.debug(f"Audio sample rate: {settings.audio.sample_rate} Hz")
    logger.debug(f"GPIO pin - Pan: {settings.gpio.servo_pan_pin}")
    logger.debug(f"OLED: {settings.oled.width}x{settings.oled.height} "
                f"at {settings.oled.i2c_address}")
    logger.debug(
        "OLED interface={} driver={} rotate={} eye_layout={} eyes_bias_x={} standalone_math_eyes={}",
        settings.oled.interface,
        settings.oled.oled_driver,
        settings.oled.rotate,
        settings.oled.eye_layout,
        settings.oled.eyes_bias_x,
        settings.oled.standalone_math_eyes,
    )

    # List audio devices and log selected devices
    logger.info("Audio configuration:")
    logger.info(f"  Sample rate: {settings.audio.sample_rate} Hz")
    logger.info(f"  Channels: {settings.audio.channels}")
    logger.info(f"  Volume: {settings.audio.volume}")
    logger.info(f"  Input device: {settings.audio.input_device or 'default'}")
    logger.info(f"  Output device: {settings.audio.output_device or 'default'}")
    list_audio_devices()

    maybe_start_standalone_face(settings)

    api_client = None
    dispatcher = None

    if settings.polling.enabled:
        # Initialise API client and dispatcher
        api_client = ApiClient(settings)
        dispatcher = Dispatcher(settings, api_client=api_client)

        # Register real driver entry-points (hardware-backed implementations will be
        # added in Phases 3–5; current versions are safe stubs in their own modules).
        # Note: speak() and listen() will receive additional args (settings/api_client) from dispatcher
        dispatcher.register_driver(ActionEnum.SPEAK, speak)
        dispatcher.register_driver(ActionEnum.LISTEN, listen)
        dispatcher.register_driver(ActionEnum.SHOW_FACE, show_face)
        dispatcher.register_driver(ActionEnum.MOVE_HEAD, move_head)
        dispatcher.register_driver(ActionEnum.SHOW_UI, show_ui)

        # Health check at startup
        await api_client.health_check()
        logger.info("Entering backend polling loop...")
    else:
        logger.info("Polling disabled: running in local standalone mode")

    # When polling is off, still wake the loop quickly for UI event logging / local use.
    loop_sleep_sec = (
        settings.polling.interval_seconds
        if settings.polling.enabled
        else min(settings.polling.interval_seconds, 0.25)
    )

    try:
        while running:
            try:
                if settings.polling.enabled and api_client is not None and dispatcher is not None:
                    cmd = await api_client.poll_command()
                    if cmd:
                        logger.info(
                            "Received command: action={} id={}",
                            cmd.action.value,
                            cmd.command_id,
                        )
                        ack = await dispatcher.execute(cmd)
                        await api_client.send_ack(ack)

                # Drain local UI events (queue may hold more than one batch).
                while True:
                    batch = dequeue_ui_events(max_items=64)
                    if not batch:
                        break
                    for ui_event in batch:
                        if api_client is not None:
                            posted = await api_client.post_ui_event(ui_event)
                            if not posted:
                                logger.info("UI event (not posted): {}", ui_event)
                        else:
                            logger.info("UI event: {}", ui_event)

                sleep_for = loop_sleep_sec
                if has_pending_ui_events():
                    sleep_for = min(sleep_for, 0.05)
                await asyncio.sleep(sleep_for)
            except Exception as e:  # noqa: BLE001
                logger.exception("Error in polling loop: {}", e)
                await asyncio.sleep(loop_sleep_sec)
    finally:
        # Stop OLED animator before releasing the device (avoid concurrent use).
        await stop_standalone_face()
        await asyncio.gather(
            shutdown_head(),
            shutdown_face(),
            *( [api_client.aclose()] if api_client is not None else [] ),
            return_exceptions=True,
        )
        logger.info("Shutdown complete")


if __name__ == "__main__":
    from env_bootstrap import load_agent_env_files

    load_agent_env_files(Path(__file__).resolve().parent)

    # Register signal handlers for graceful shutdown
    signal.signal(signal.SIGINT, handle_shutdown)
    signal.signal(signal.SIGTERM, handle_shutdown)

    try:
        asyncio.run(main())
    except KeyboardInterrupt:
        logger.info("Interrupted by user")
        sys.exit(0)
    except Exception as e:
        logger.exception(f"Fatal error: {e}")
        sys.exit(1)

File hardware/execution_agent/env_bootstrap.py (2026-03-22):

"""Load `.env` files in a fixed order for the execution agent and LangGraph.

Later files override earlier ones (same behaviour as the former `run_gui.py` logic).
"""

from __future__ import annotations

from pathlib import Path


def find_repo_root(start: Path) -> Path:
    for p in [start, *start.parents]:
        if (p / "agentic" / "graph.py").is_file():
            return p
    return start.parent


def load_agent_env_files(execution_agent_dir: Path | None = None) -> None:
    """Merge env from repo root, backend, agentic/db, execution_agent, then hardware/."""
    try:
        from dotenv import load_dotenv
    except ImportError:
        return

    agent_dir = execution_agent_dir or Path(__file__).resolve().parent
    repo_root = find_repo_root(agent_dir)
    candidates = [
        repo_root / ".env",
        repo_root / "backend" / ".env",
        repo_root / "agentic" / "db" / ".env",
        agent_dir / ".env",
        agent_dir.parent / ".env",
    ]
    for path in candidates:
        if path.is_file():
            load_dotenv(path, override=True)


__all__ = ["load_agent_env_files", "find_repo_root"]

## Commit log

2025-12-23 Added some more parts list on the hardware and discription aabout raspberry pi os installation.
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2026-01-22 updated the My Patients page under the therapist
2026-01-23 Designed and 3D printed the internal frame(Raspberry Pi frame) of the robot
    [waabi_base_skeleton.stl]
2026-01-25 Updated sidebar for patient dashboard and added patient profile page with static data
2026-01-30 added supabase configuration for therapist and finished therapist profile and patient page
2026-01-31 Add STL file for Waabi frame body design
    [waabi_frame-Body.stl]
2026-02-01 Fix Supabase URL initialization and format response structures in health check and start session endpoints
    [main.py]
2026-02-01 Fix Supabase URL initialization to use environment variable
    [main.py]
2026-02-02 updated sessions inside patient portal to update only if the patient has selected a speech therapist
2026-02-07 Fix Supabase key environment variable name in main.py
    [main.py]
2026-02-07 Function signature fixed and logger
    fixed function signature mismatch in main.py - now passes semantic_report to reasoning node.Fixed logger to use correct error_type field
    [main.py]
2026-02-08 Fixed supabase service key naming error
    [main.py]
2026-02-08 Fixed booking feature for sessions and syncing bewteen speech therapist and patient
2026-02-09 Updated the chat page in the patient portal
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2026-02-10 Add installation and setup scripts for execution agent on Raspberry Pi
2026-02-11 Updated the My words page in the patient portal
2026-02-11 Add main entry point, settings management, and audio I/O drivers (ear/mouth) with hardware abstraction and mock fallbacks for development environments.
2026-03-03 creatred sentence_analyzer.py
    this is used to compare the target and spoken sentence to find the words missing , three errors focused are substituitons , omissions and insertions
2026-03-08 3d Design of the waabi 's body (front & back plate)
    [waabi_frame-Body005.stl, waabi_frame-Body006.stl]
2026-03-08 Deleted the Agentic Folder
    The folder contained codes that is no longer needed , a brand new code will be comitted soon
    [main.py]
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2026-03-11 updated bcak plate design
    [waabi_frame-Body006.stl]
2026-03-11 refactor: update dispatcher to use real driver implementations for ear and mouth services
2026-03-11 add face and head service drivers for robot control
2026-03-12 Changes in the My Profile page in the Patient and Therapist portals
2026-03-12 updated perception node
    specified data type of current error
2026-03-13 Updated MyWords.jsx and PatientLayout.jsx to fix ci workflow
2026-03-14 updated front plate design
    [waabi_frame-Body005.stl]
2026-03-16 Design files of the side plate
    [waabi_frame-Body007.stl, waabi_frame-Body008.stl]
2026-03-17 Enhance audio handling in main.py and ear.py with device logging and improved recording functionality
2026-03-17 Enhance Dispatcher to support additional context for driver execution and error handling
2026-03-17 Add audio utilities for device selection and listing functionality
2026-03-17 Updated my sessions page to assign and change speech therapists for each patient, all speech therapits get access to patient data
2026-03-17 fixed ci workflow for patient layout file
2026-03-17 fixed ci workflow under my patients
2026-03-17 updated my patients supabase updates to assigned speech therapist
2026-03-18 Updated design files and renamed it
    [waabi_frame-Back_plate.stl, waabi_frame-BaseV2.stl, waabi_frame-Body005.stl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]
2026-03-18 updated patient profile to sync with supabase, updated therapist my patient page to not auto save and add new sessions, update sessions page on patient portal to show all current sessions scheduled
2026-03-18 Font and color palette changed in the patient portal
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2026-03-19 Refactor head driver for pan-only control and improve shutdown handling
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2026-03-19 updated my patients csv file format and integrated to supabase properly
2026-03-20 updated my patients in therapist portal to give the therapist to enter either target words or sentence
2026-03-20 fixed backend agentic error
    [main.py]
2026-03-20 updated my sessions font and color change, updated my patients csv files
2026-03-20 Updated the chat system for the patient and therapist portals
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2026-03-20 fixed patient layout ui bugs
2026-03-20 Add UI components for therapy application in Kivy
    - Introduced a new Kivy file `body_app.kv` containing UI definitions.
    - Created custom button styles: `RoundedBlueButton`, `CategoryCard`, and `BackButton`.
    - Implemented layout structures for various screens: `HomeScreen`, `CategorySelectionScreen`, `PracticeWordScreen`, `EmptyStateScreen`, `FeedbackScreen`, and `SettingsScreen`.
    - Added visual elements including headers, labels, buttons, and progress bars with appropriate styling and functionality.
2026-03-20 Add SPI support and update OLED configuration in README and test scripts
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2026-03-21 waabi head design files
    [waabi_frame-Body011.stl, waabi_frame-Body012.stl]
2026-03-21 Fixed the navigation bar issue in the patient layout
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2026-03-21 Add Kivy UI for Speech Therapy Application
    - Implement body_app.kv for UI layout including buttons, screens, and panels.
    - Create body_app.py to manage application logic, screen transitions, and state management.
    - Introduce test_practice_screen.py to facilitate testing of the practice screen functionality.
    - Define UI components such as RoundedBlueButton, CategoryCard, and various screens for home, category selection, practice, feedback, and settings.
    - Establish a queue system for UI events and commands to handle asynchronous updates.
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2026-03-22 Updated the design in the agent session trace page in the therapist portal
2026-03-22 Fixed a small bug in the chat page of the patient portal
2026-03-22 Refactor environment loading and enhance audio processing
    - Introduced a new `_load_standard_env_files` function in `supabase_store.py` to load environment variables from multiple `.env` files in a specific order.
    - Updated `execution_node.py` to improve audio output handling by discovering the laptop's default speaker and playing TTS audio through it.
    - Enhanced the `_speak` function to handle audio playback more robustly, including fallback mechanisms.
    - Modified `perception_node.py` to improve device detection for USB microphones and added resampling for Whisper accuracy.
    - Added a new `history_node.py` to fetch session history and trends from Supabase and Mem0.
    - Created `env_bootstrap.p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
